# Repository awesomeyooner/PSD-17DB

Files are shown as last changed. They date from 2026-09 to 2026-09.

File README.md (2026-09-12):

# PSD-17DB
This is a breakout board mainly for the DRV8874, but includes other ICs that help with integrating FOC. About the name, it is short for "Polar Stepper Drive 17 - Dev Board". Polar because I like polar bears and 17 for usage with NEMA 17 stepper motors. 

I designed this to go ontop of my [Tiny Thinker STM32](https://github.com/awesomeyooner/Tiny-Thinker) board.

## Features

- Dual [DRV8874 DC Motor Drivers](https://www.ti.com/lit/ds/symlink/drv8874.pdf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) to control each phase
- [TPS16630](https://www.ti.com/lit/ds/symlink/tps1663.pdf?ts=1789169253557&ref_url=https%253A%252F%252Fwww.mouser.com%252F) mainly for inrush current protection (due to high capacitance)
- [BL9342 5V Step down converter](https://www.alldatasheet.com/datasheet-pdf/view/1033628/BELLING/BL9342.html) for powering the MCU using a battery
- Integrated [CAN Transciever](https://www.ti.com/lit/ds/symlink/sn65hvd230.pdf) for `CAN2.0B`
- [32Kbit SPI EEPROM](https://www.st.com/resource/en/datasheet/m95320-w.pdf) for storing parameters like `CAN ID`, `Eccentricity Offsets`, `Electrical Offset`, etc
- 4 [WS2812B RGB LEDs](https://mm.digikey.com/Volume0/opasdata/d220001/medias/docus/8903/XL-0807RGBC-WS2812B.pdf) for status lights
- R-Divider for input voltage sensing using ADC

## Pictures

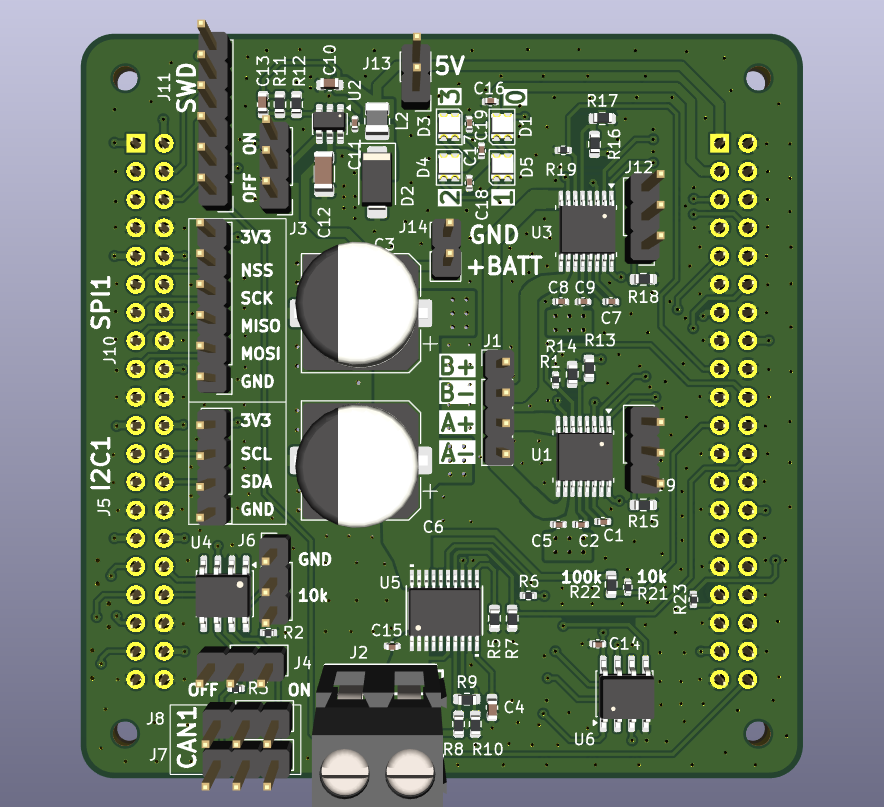
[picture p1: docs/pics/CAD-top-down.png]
CAD-top-down


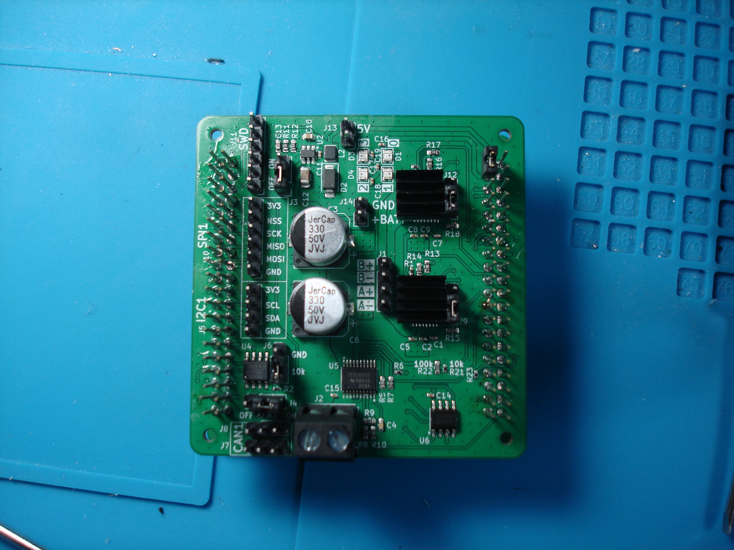
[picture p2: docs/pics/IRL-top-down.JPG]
IRL-top-down


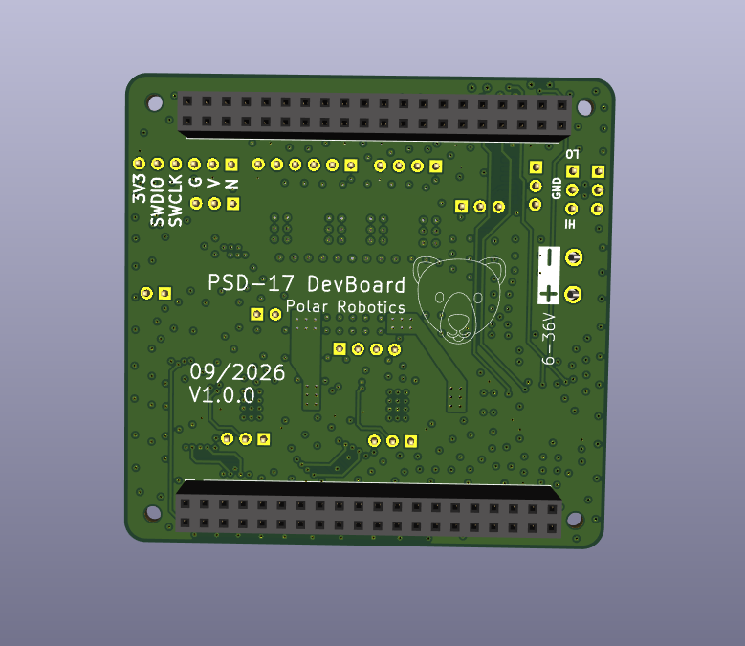
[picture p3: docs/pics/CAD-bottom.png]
CAD-bottom


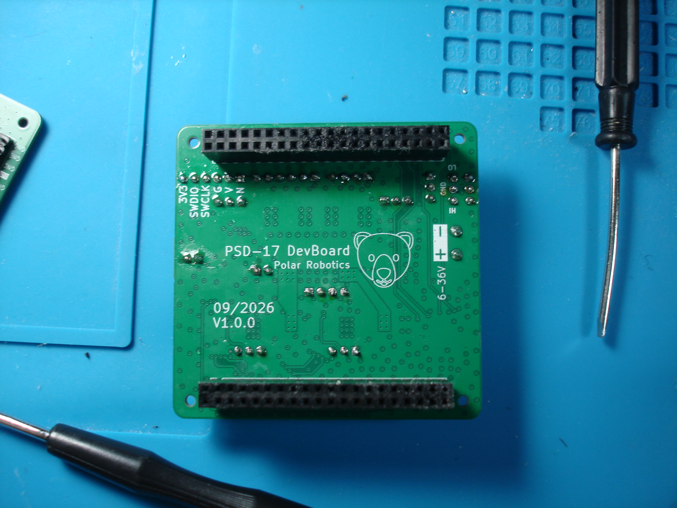
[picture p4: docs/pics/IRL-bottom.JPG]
IRL-bottom


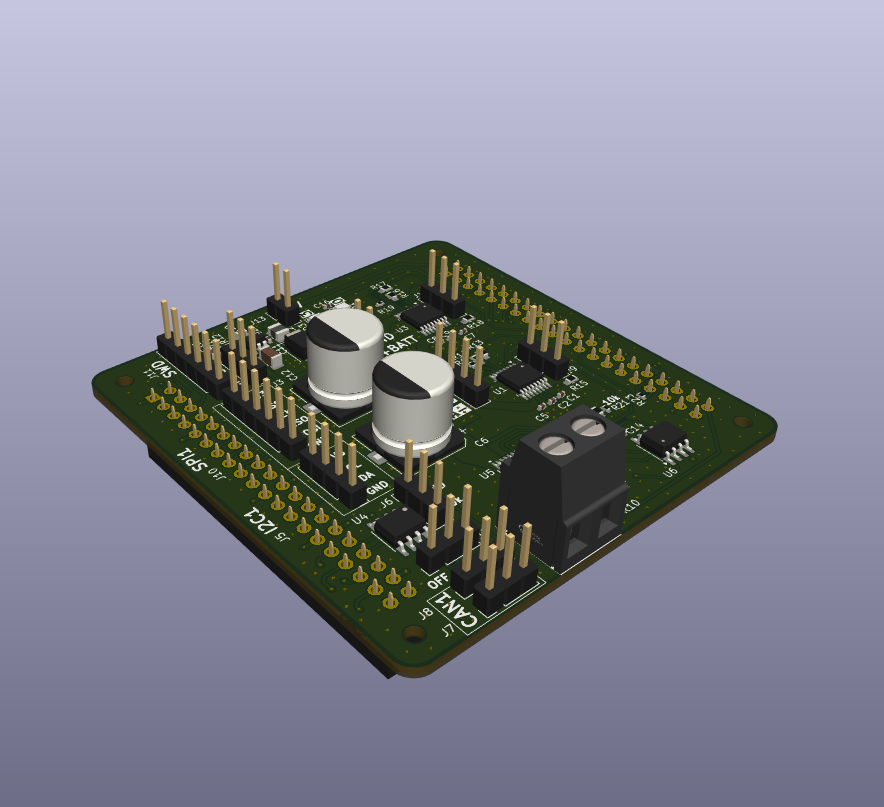
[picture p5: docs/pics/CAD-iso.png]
CAD-iso


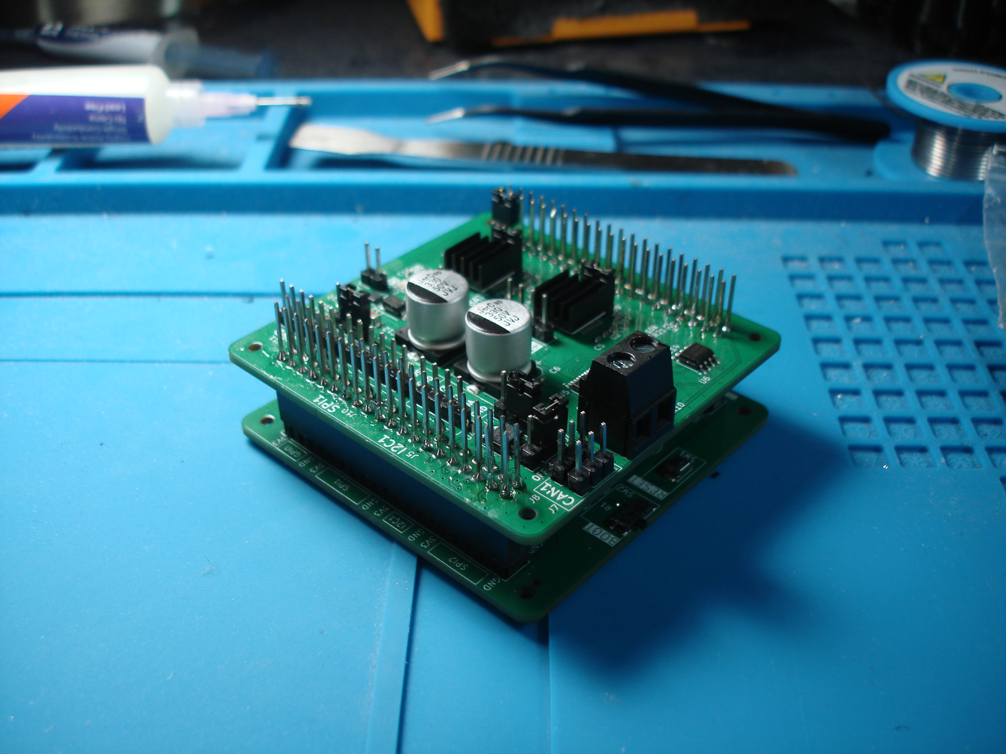
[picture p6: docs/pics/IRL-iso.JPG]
IRL-iso


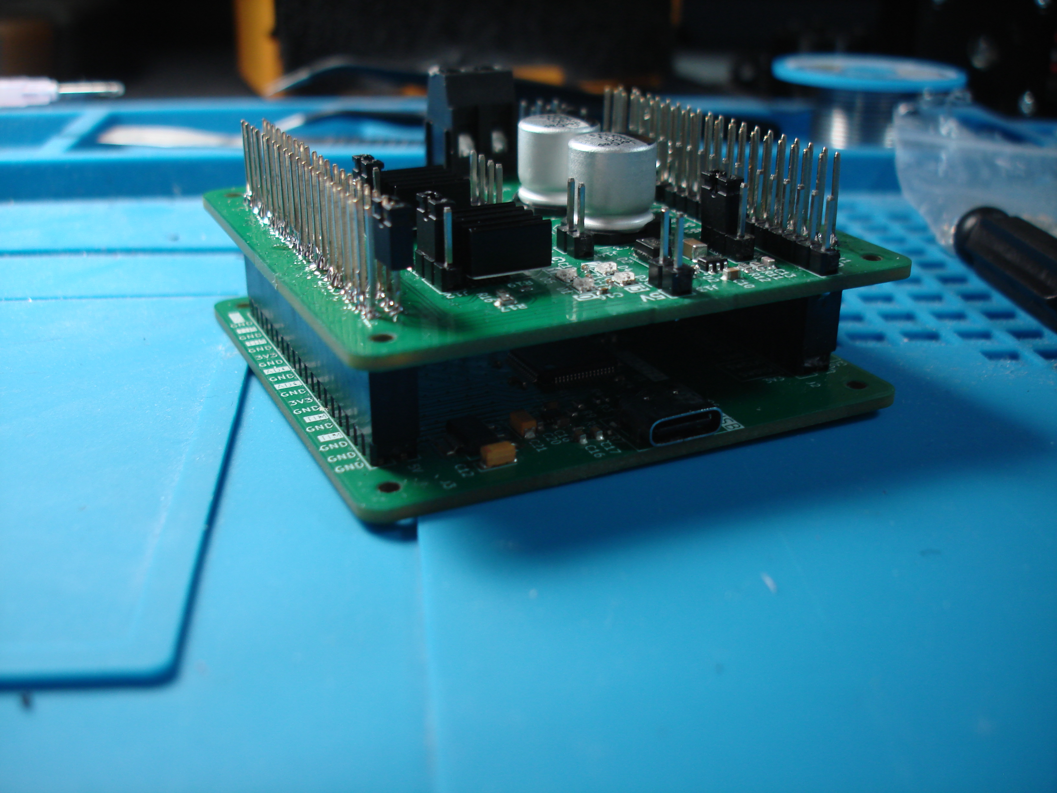
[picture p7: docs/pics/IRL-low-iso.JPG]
IRL-low-iso


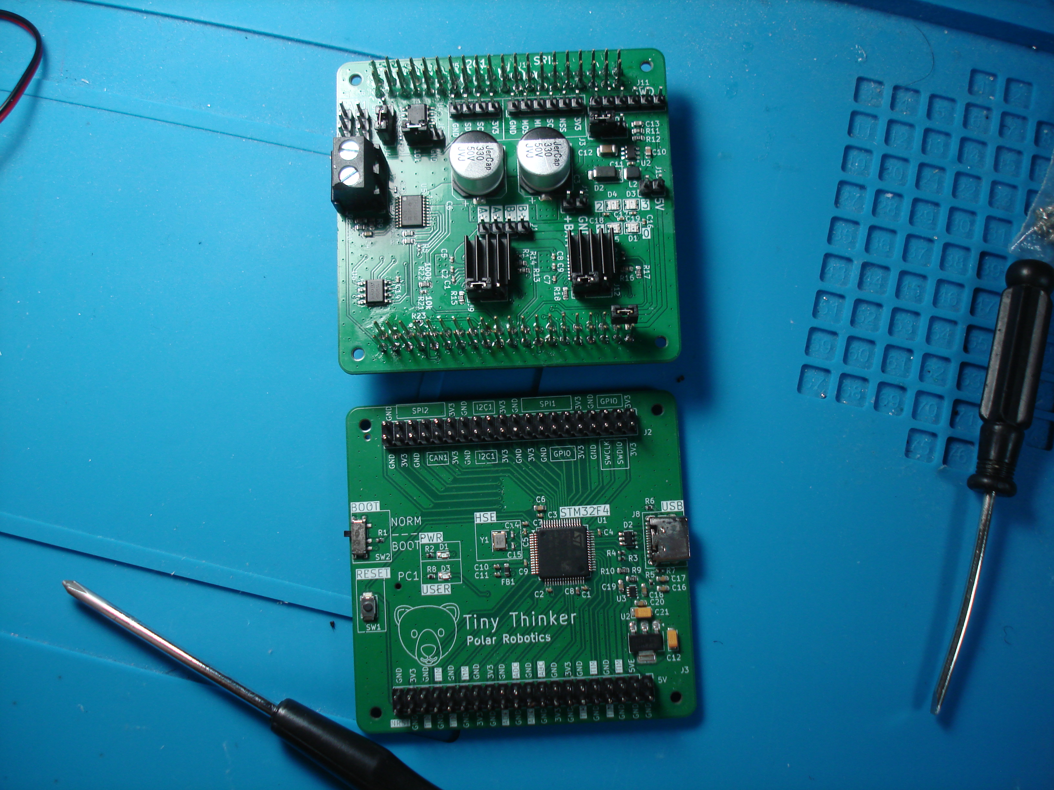
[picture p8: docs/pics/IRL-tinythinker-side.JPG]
IRL-tinythinker-side


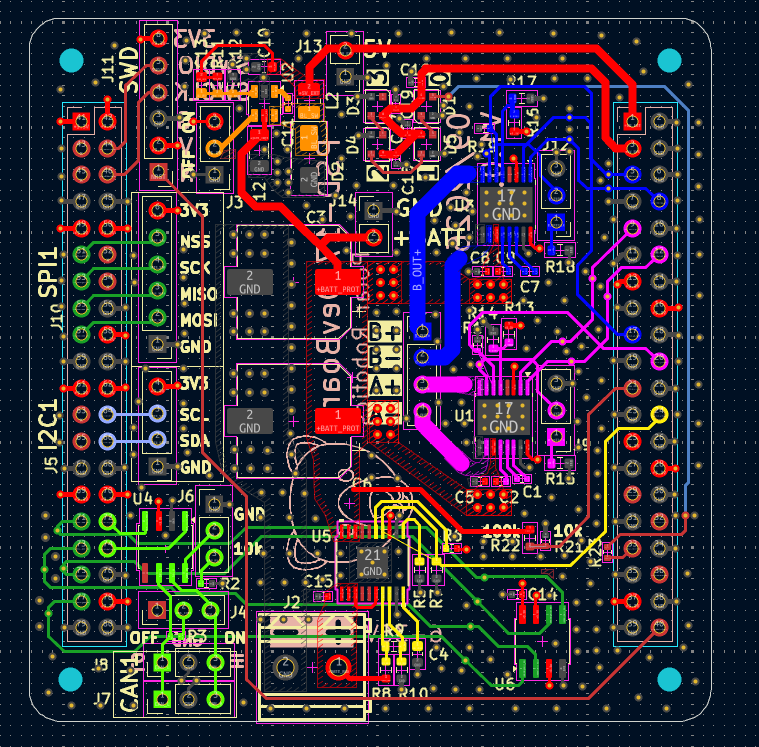
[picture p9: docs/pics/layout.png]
layout


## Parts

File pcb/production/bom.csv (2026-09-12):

Designator | Footprint | Quantity | Value | LCSC Part #
C1, C7 | 0402 | 2 | 22nF | C1532
C10 | 0603 | 1 | 10uF | C96446
C11, C14, C15, C16, C17, C18, C19, C2, C5, C8, C9 | 0402 | 11 | 100nF | C307331
C12 | 1206 | 1 | 4.7uF | C29823
C13 | 0603 | 1 | 33pF | C1663
C3, C6 | CP_Elec_10x10.5 | 2 | 330uF | C46550419
C4 | 0603 | 1 | 33nF | C21117
D1, D3, D4, D5 | LED_WS2812B-2020_PLCC4_2.0x2.0mm | 4 | WS2812B-2020 | C3646929
D2 | D_SMA | 1 | D_Schottky | C2480
J1, J5 | PinHeader_1x04_P2.54mm_Vertical | 2 | Conn_01x04_Pin
J10, J11 | PinHeader_1x06_P2.54mm_Vertical | 2 | Conn_01x06_Pin
J12, J3, J4, J6, J7, J8, J9 | PinHeader_1x03_P2.54mm_Vertical | 7 | Conn_01x03_Pin
J13, J14 | PinHeader_1x02_P2.54mm_Vertical | 2 | Conn_01x02_Pin
J2 | CONN-TH_2P-P5.08_DB128L-5.08-2P-BK-S | 1 | Screw_Terminal_01x02 | C430601
L2 | 1008 | 1 | 4u7 | C5832360
R1, R19 | 0402 | 2 | 2k2 | C25879
R10, R15, R18 | 0603 | 3 | 20k | C4184
R11 | 0603 | 1 | 124k | C22788
R12 | 0603 | 1 | 23k7 | C2933175
R13, R16 | 0603 | 2 | 15k | C22809
R14, R17 | 0603 | 2 | 75k | C23242
R2, R21, R6 | 0402 | 3 | 10k | C25744
R22, R9 | 0603 | 2 | 100k | C25803
R23 | 0402 | 1 | 470 | C25117
R3 | 0402 | 1 | 120 | C25079
R5 | 0603 | 1 | 3k | C4211
R7 | 0603 | 1 | 18k | C25810
R8 | 0603 | 1 | 510k | C23192
U1, U3 | HTSSOP-16-1EP_4.4x5mm_P0.65mm_EP3.4x5mm_Mask2.46x2.31mm | 2 | DRV8874 | C1855818
U2 | SOT-23-6 | 1 | BL9342 | C93176
U4 | SOIC-8_3.9x4.9mm_P1.27mm | 1 | SN65HVD230 | C12084
U5 | HTSSOP20_PWP_TEX | 1 | TPS16630PWPR | C1849461
U6 | SO-8_3.9x4.9mm_P1.27mm | 1 | M95320-WMN6TP | C283459
U7 | TinyThinker_HAT | 1 | TinyThinker_J1 | C1525

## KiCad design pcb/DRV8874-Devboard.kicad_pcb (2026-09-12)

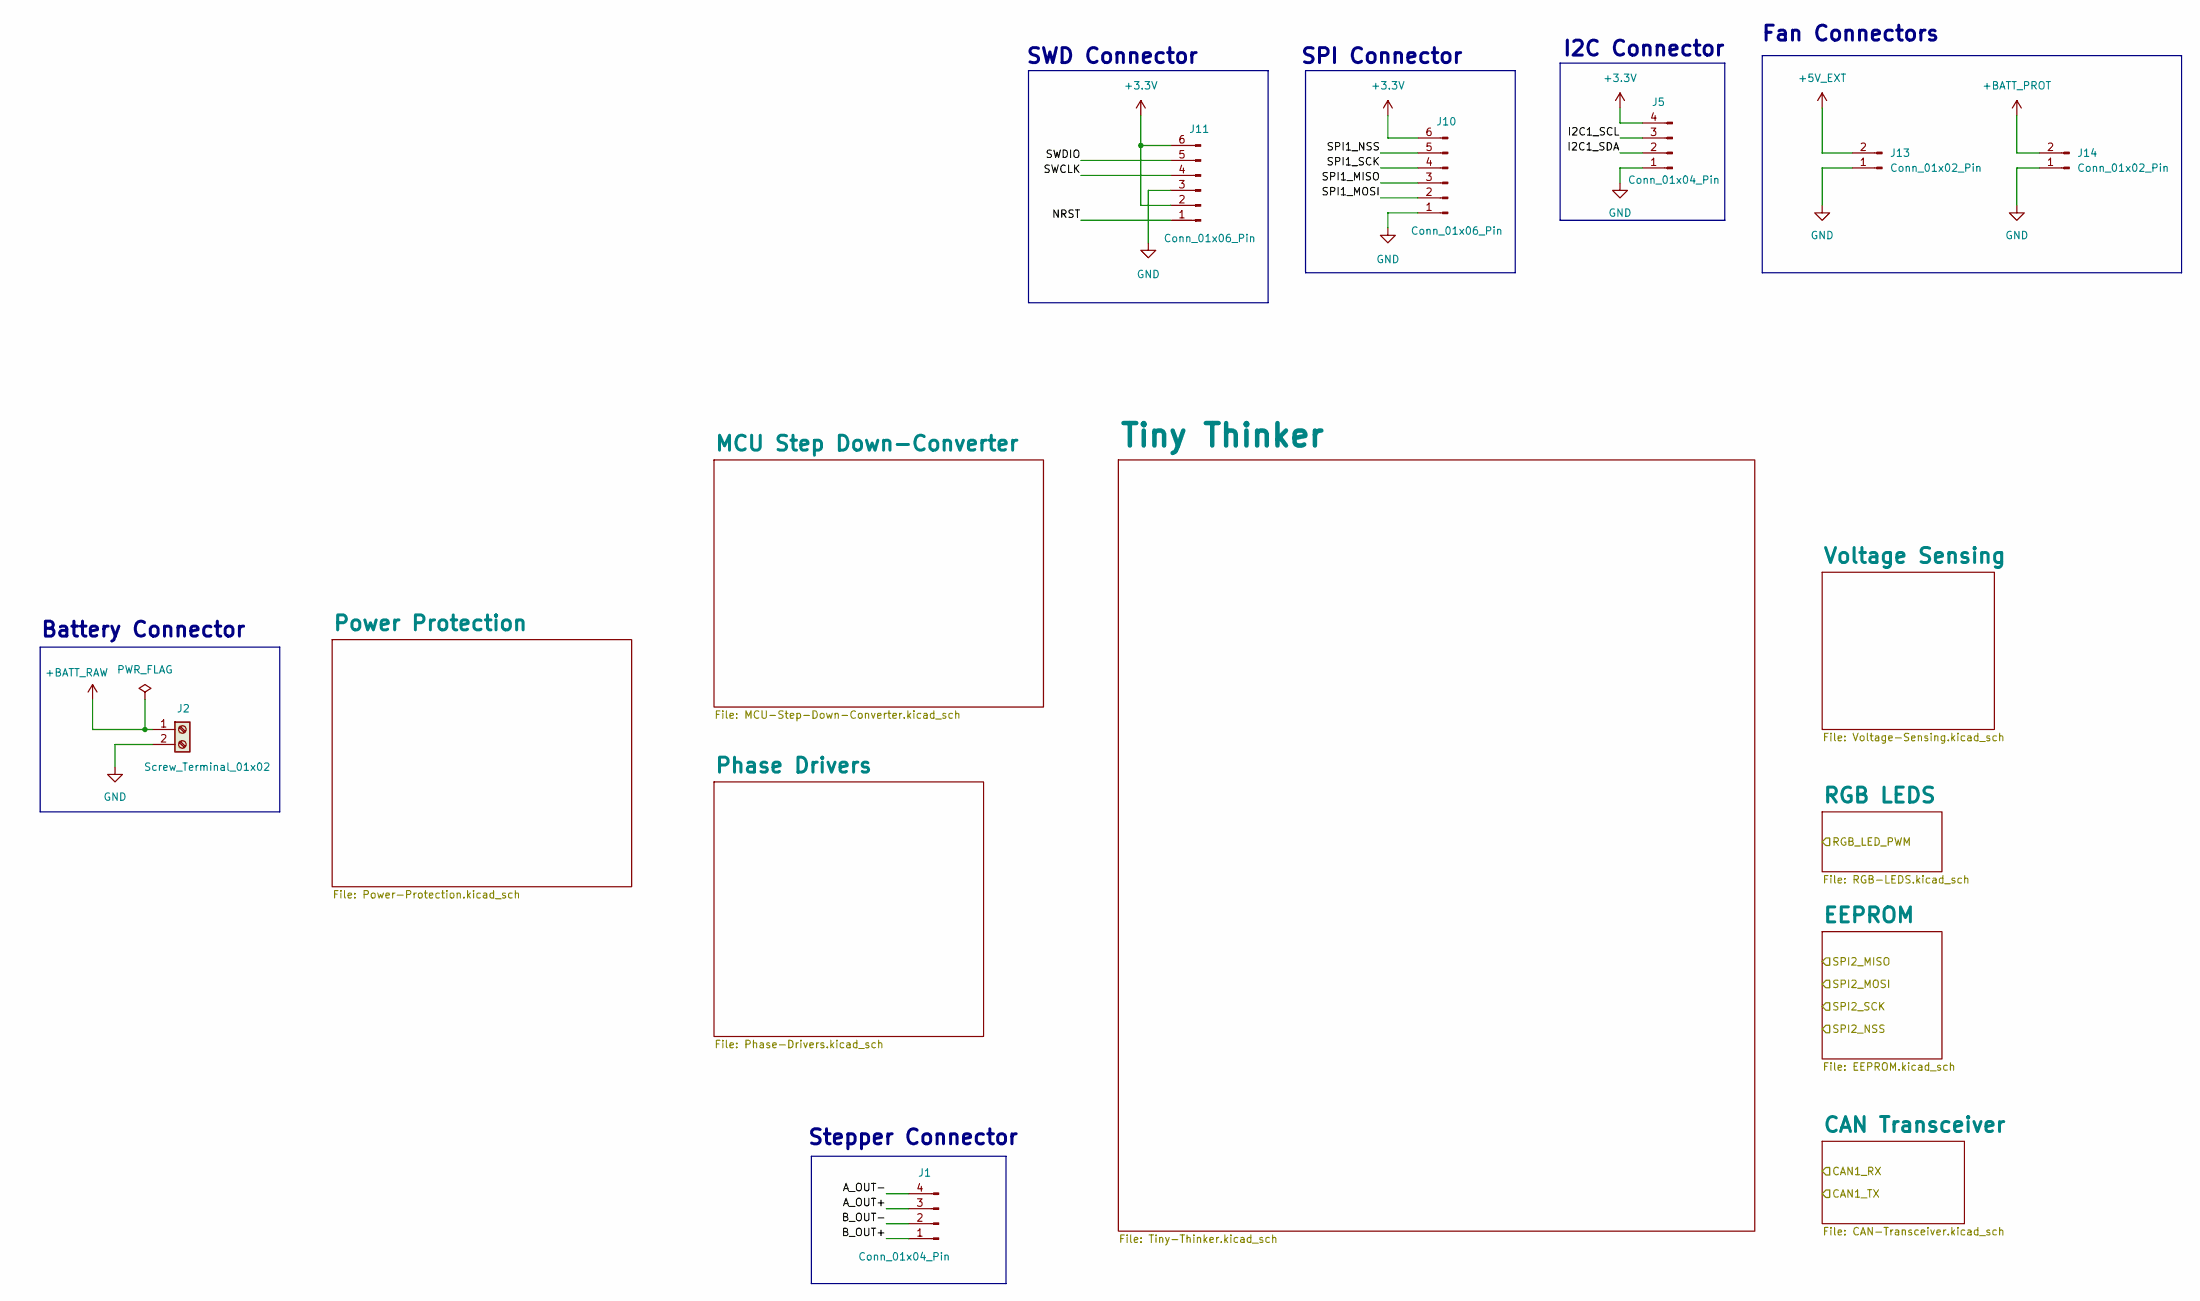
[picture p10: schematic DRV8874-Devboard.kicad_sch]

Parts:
J1, J5: Conn_01x04_Pin; PinHeader_1x04_P2.54mm_Vertical
J2: Screw_Terminal_01x02; CONN-TH_2P-P5.08_DB128L-5.08-2P-BK-S; JLCPCB Part # C430601
J10, J11: Conn_01x06_Pin; PinHeader_1x06_P2.54mm_Vertical
J13, J14: Conn_01x02_Pin; PinHeader_1x02_P2.54mm_Vertical

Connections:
+3.3V: J5.4, J10.6, J11.2, J11.6; also elsewhere on the board
+5V_EXT: J13.2; also elsewhere on the board
+BATT_PROT: J14.2; also elsewhere on the board
+BATT_RAW: J2.1; also elsewhere on the board
/A_OUT+: J1.3
/A_OUT-: J1.4
/B_OUT+: J1.1
/B_OUT-: J1.2
/I2C1_SCL: J5.3
/I2C1_SDA: J5.2
/NRST: J11.1
/SPI1_MISO: J10.3
/SPI1_MOSI: J10.2
/SPI1_NSS: J10.5
/SPI1_SCK: J10.4
/SWCLK: J11.4
/SWDIO: J11.5
GND: J2.2, J5.1, J10.1, J11.3, J13.1, J14.1; also elsewhere on the board

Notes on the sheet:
SWD Connector
Fan Connectors
Battery Connector
SPI Connector
Stepper Connector
I2C Connector

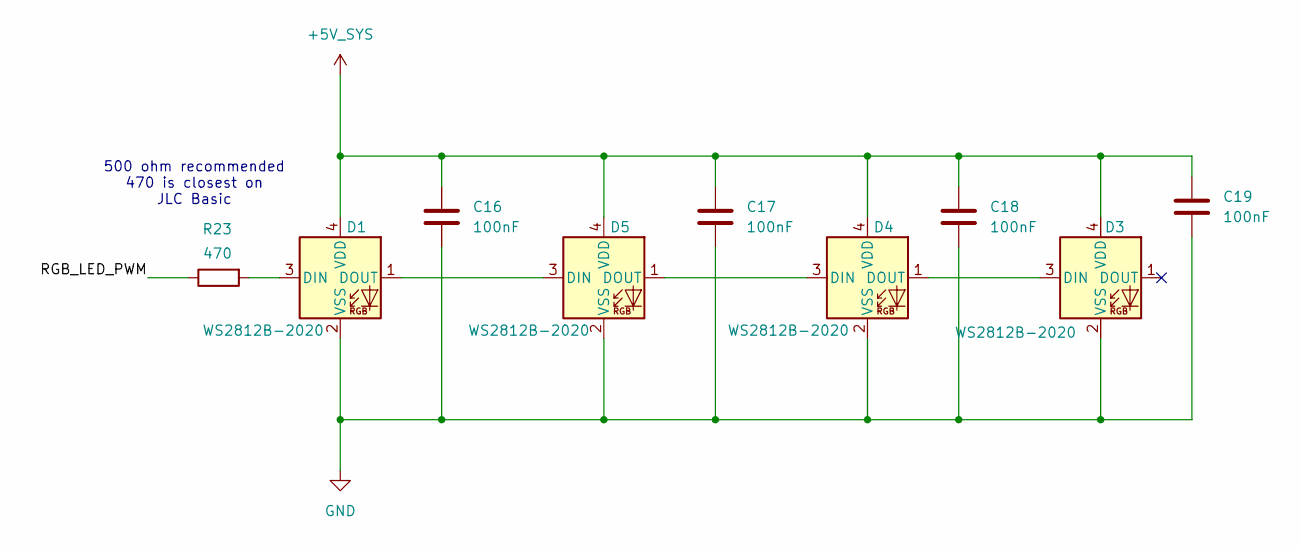
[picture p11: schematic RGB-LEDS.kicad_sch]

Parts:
C16, C17, C18, C19: 100nF; C_0402_1005Metric; JLCPCB Part # C307331
D1, D3, D4, D5: WS2812B-2020; LED_WS2812B-2020_PLCC4_2.0x2.0mm; JLCPCB Part # C3646929
R23: 470; R_0402_1005Metric; JLCPCB Part # C25117

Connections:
+5V_SYS: C16.1, C17.1, C18.1, C19.1, D1.4 (VDD), D3.4 (VDD), D4.4 (VDD), D5.4 (VDD); also elsewhere on the board
/RGB LEDS/RGB_LED_PWM: R23.1
GND: C16.2, C17.2, C18.2, C19.2, D1.2 (VSS), D3.2 (VSS), D4.2 (VSS), D5.2 (VSS); also elsewhere on the board
unnamed: D1.3 (DIN), R23.2
unnamed: D1.1 (DOUT), D5.3 (DIN)
unnamed: D3.3 (DIN), D4.1 (DOUT)
unnamed: D4.3 (DIN), D5.1 (DOUT)

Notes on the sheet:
500 ohm recommended 470 is closest on JLC Basic

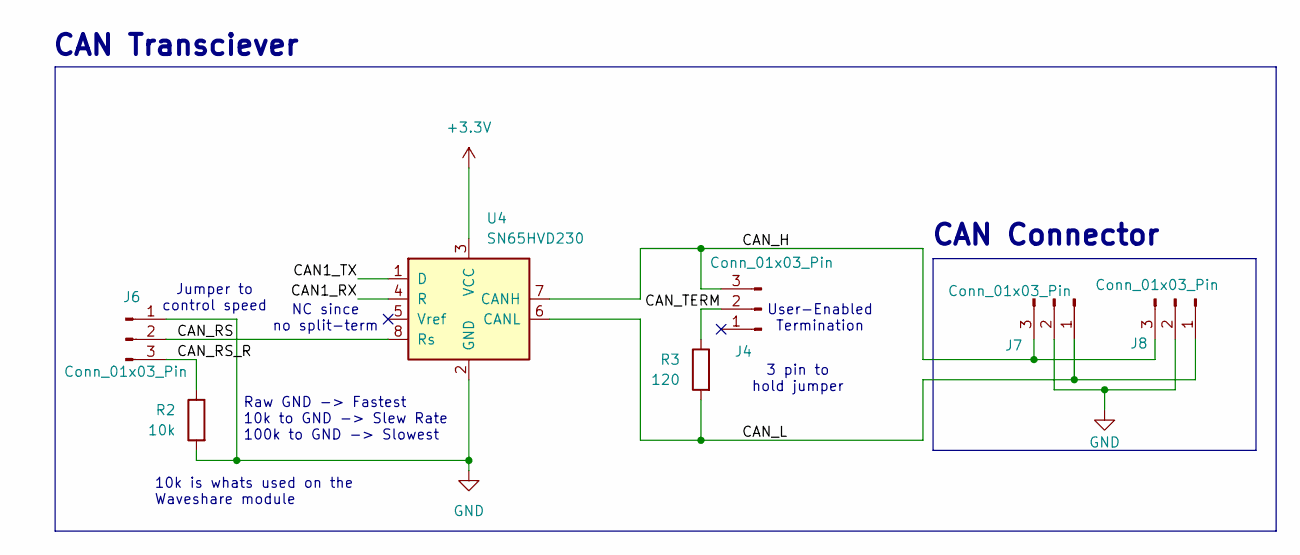
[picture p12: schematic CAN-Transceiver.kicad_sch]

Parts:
J4, J6, J7, J8: Conn_01x03_Pin; PinHeader_1x03_P2.54mm_Vertical
R2: 10k; R_0402_1005Metric; JLCPCB Part # C25744
R3: 120; R_0402_1005Metric; JLCPCB Part # C25079
U4: SN65HVD230; SOIC-8_3.9x4.9mm_P1.27mm; JLCPCB Part # C12084

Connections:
+3.3V: U4.3 (VCC); also elsewhere on the board
/CAN Transceiver/CAN1_RX: U4.4 (R)
/CAN Transceiver/CAN1_TX: U4.1 (D)
/CAN Transceiver/CAN_H: J4.3, J7.3, J8.3, U4.7 (CANH)
/CAN Transceiver/CAN_L: J7.1, J8.1, R3.2, U4.6 (CANL)
/CAN Transceiver/CAN_RS: J6.2, U4.8 (Rs)
/CAN Transceiver/CAN_RS_R: J6.3, R2.1
/CAN Transceiver/CAN_TERM: J4.2, R3.1
GND: J6.1, J7.2, J8.2, R2.2, U4.2 (GND); also elsewhere on the board

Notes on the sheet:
Jumper to control speed
10k is whats used on the Waveshare module
CAN Connector
CAN Transciever
Raw GND -> Fastest 10k to GND -> Slew Rate 100k to GND -> Slowest
3 pin to hold jumper
User-Enabled Termination
NC since no split-term

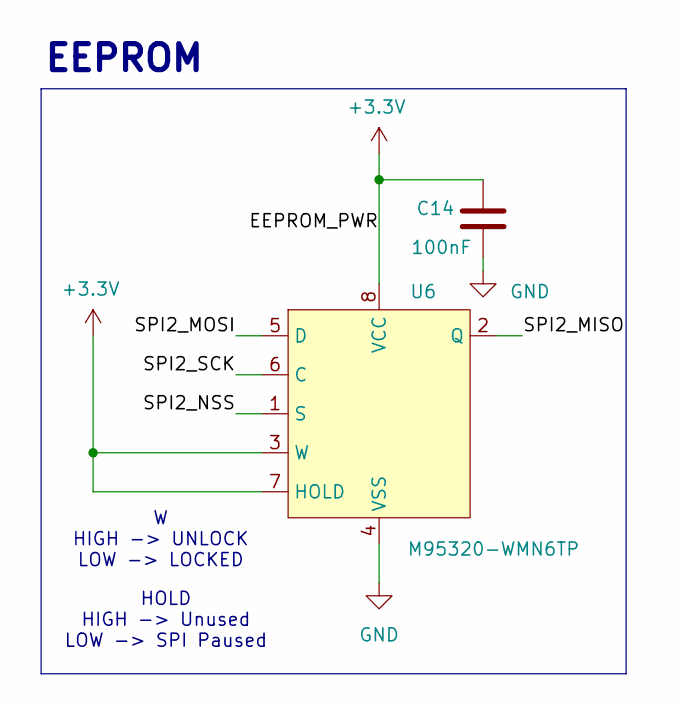
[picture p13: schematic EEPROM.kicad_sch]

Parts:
C14: 100nF; C_0402_1005Metric; JLCPCB Part # C307331
U6: M95320-WMN6TP; SO-8_3.9x4.9mm_P1.27mm; JLCPCB Part # C283459

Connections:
+3.3V: C14.1, U6.3 (W), U6.7 (HOLD), U6.8 (VCC); also elsewhere on the board
/EEPROM/SPI2_MISO: U6.2 (Q)
/EEPROM/SPI2_MOSI: U6.5 (D)
/EEPROM/SPI2_NSS: U6.1 (S)
/EEPROM/SPI2_SCK: U6.6 (C)
GND: C14.2, U6.4 (VSS); also elsewhere on the board

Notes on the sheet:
HOLD HIGH -> Unused LOW -> SPI Paused
EEPROM
W HIGH -> UNLOCK LOW -> LOCKED

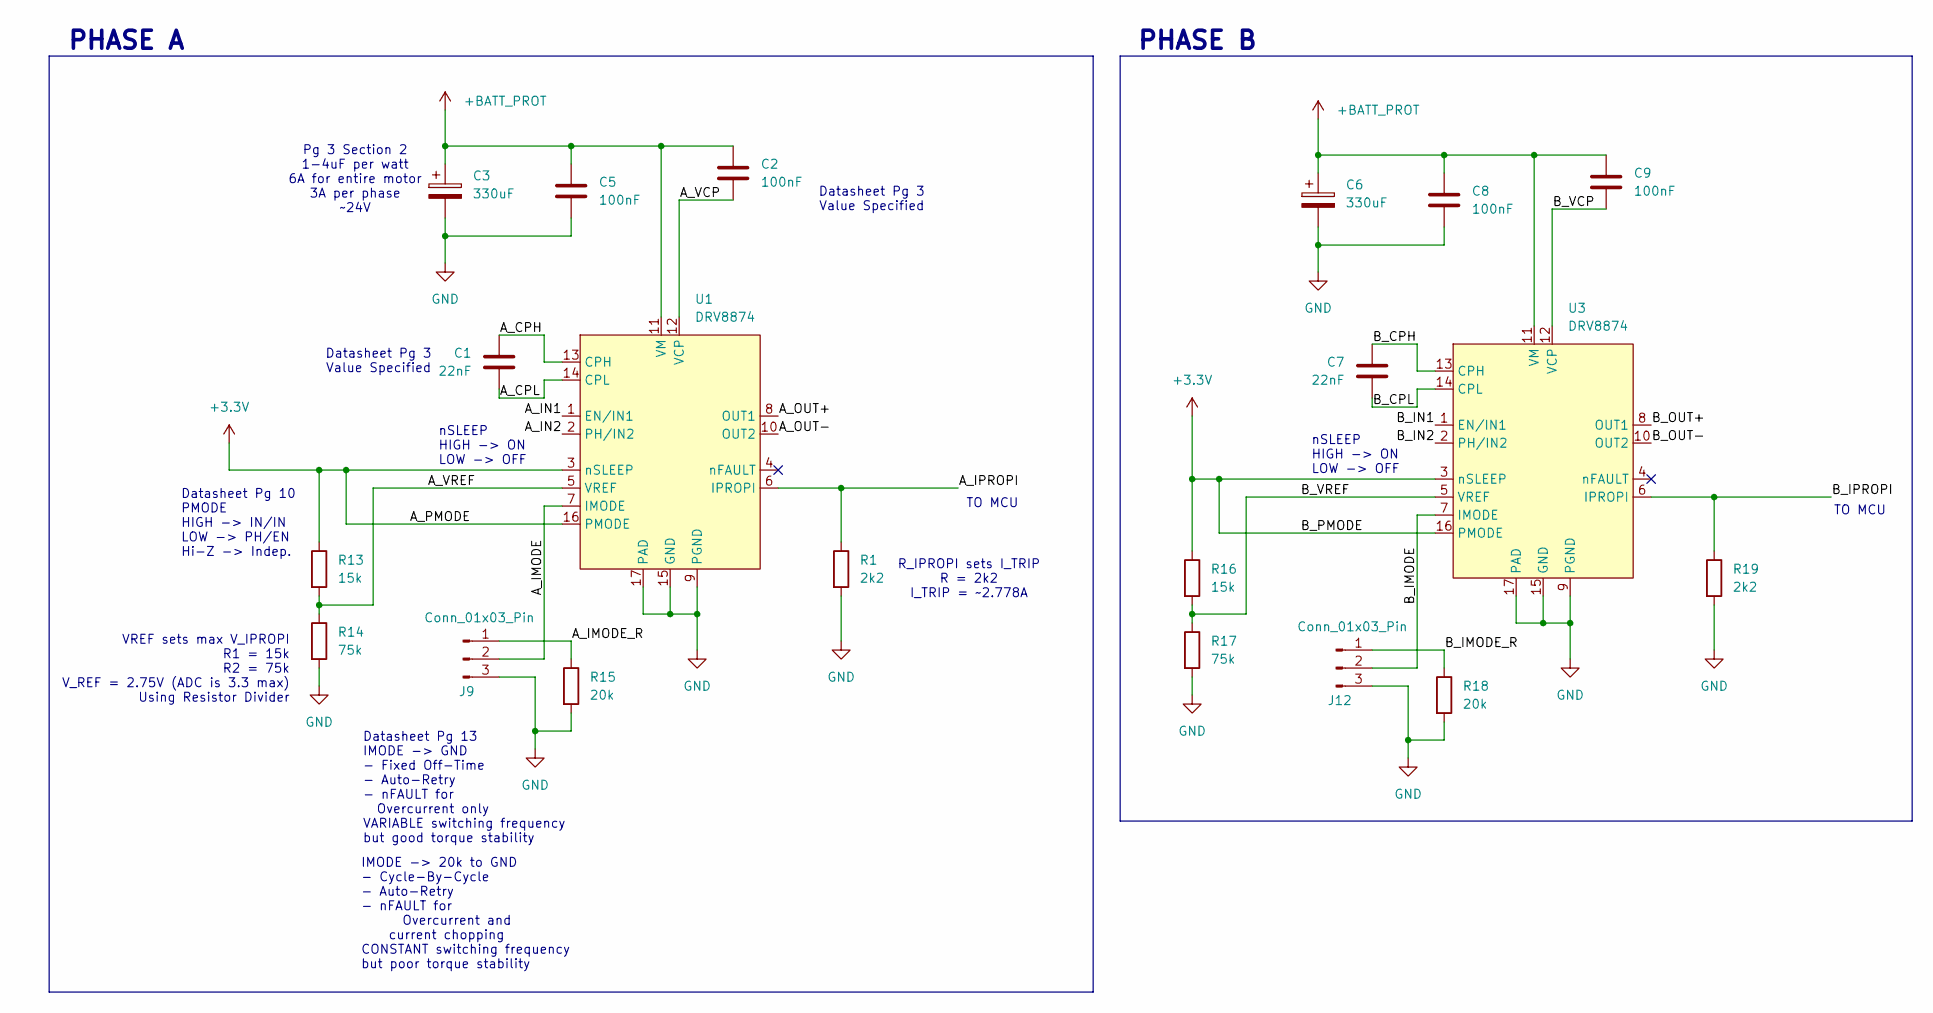
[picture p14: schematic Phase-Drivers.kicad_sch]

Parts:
C1, C7: 22nF; C_0402_1005Metric; JLCPCB Part # C1532
C2, C5, C8, C9: 100nF; C_0402_1005Metric; JLCPCB Part # C307331
C3, C6: 330uF; CP_Elec_10x10.5; JLCPCB Part # C46550419
J9, J12: Conn_01x03_Pin; PinHeader_1x03_P2.54mm_Vertical
R1, R19: 2k2; R_0402_1005Metric; JLCPCB Part # C25879
R13, R16: 15k; R_0603_1608Metric; JLCPCB Part # C22809
R14, R17: 75k; R_0603_1608Metric; JLCPCB Part # C23242
R15, R18: 20k; R_0603_1608Metric; JLCPCB Part # C4184
U1, U3: DRV8874; HTSSOP-16-1EP_4.4x5mm_P0.65mm_EP3.4x5mm_Mask2.46x2.31mm; JLCPCB Part # C1855818

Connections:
+3.3V: R13.1, R16.1, U1.3 (nSLEEP), U1.16 (PMODE), U3.3 (nSLEEP), U3.16 (PMODE); also elsewhere on the board
+BATT_PROT: C2.1, C3.1, C5.1, C6.1, C8.1, C9.1, U1.11 (VM), U3.11 (VM); also elsewhere on the board
/Phase Drivers/A_CPH: C1.1, U1.13 (CPH)
/Phase Drivers/A_CPL: C1.2, U1.14 (CPL)
/Phase Drivers/A_IMODE: J9.2, U1.7 (IMODE)
/Phase Drivers/A_IMODE_R: J9.1, R15.1
/Phase Drivers/A_IN1: U1.1 (EN/IN1)
/Phase Drivers/A_IN2: U1.2 (PH/IN2)
/Phase Drivers/A_IPROPI: R1.1, U1.6 (IPROPI)
/Phase Drivers/A_OUT+: U1.8 (OUT1)
/Phase Drivers/A_OUT-: U1.10 (OUT2)
/Phase Drivers/A_VCP: C2.2, U1.12 (VCP)
/Phase Drivers/A_VREF: R13.2, R14.1, U1.5 (VREF)
/Phase Drivers/B_CPH: C7.1, U3.13 (CPH)
/Phase Drivers/B_CPL: C7.2, U3.14 (CPL)
/Phase Drivers/B_IMODE: J12.2, U3.7 (IMODE)
/Phase Drivers/B_IMODE_R: J12.1, R18.1
/Phase Drivers/B_IN1: U3.1 (EN/IN1)
/Phase Drivers/B_IN2: U3.2 (PH/IN2)
/Phase Drivers/B_IPROPI: R19.1, U3.6 (IPROPI)
/Phase Drivers/B_OUT+: U3.8 (OUT1)
/Phase Drivers/B_OUT-: U3.10 (OUT2)
/Phase Drivers/B_VCP: C9.2, U3.12 (VCP)
/Phase Drivers/B_VREF: R16.2, R17.1, U3.5 (VREF)
GND: C3.2, C5.2, C6.2, C8.2, J9.3, J12.3, R1.2, R14.2, R15.2, R17.2, R18.2, R19.2, U1.9 (PGND), U1.15 (GND), U1.17 (PAD), U3.9 (PGND), U3.15 (GND), U3.17 (PAD); also elsewhere on the board

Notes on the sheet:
Datasheet Pg 3 Value Specified
PHASE B
Datasheet Pg 13 IMODE -> GND - Fixed Off-Time - Auto-Retry - nFAULT for Overcurrent only VARIABLE switching frequency but good torque stability
PHASE A
nSLEEP HIGH -> ON LOW -> OFF
VREF sets max V_IPROPI R1 = 15k R2 = 75k V_REF = 2.75V (ADC is 3.3 max) Using Resistor Divider
TO MCU
IMODE -> 20k to GND - Cycle-By-Cycle - Auto-Retry - nFAULT for Overcurrent and current chopping CONSTANT switching frequency but poor torque stability
Pg 3 Section 2 1-4uF per watt 6A for entire motor 3A per phase ~24V
R_IPROPI sets I_TRIP R = 2k2 I_TRIP = ~2.778A
Datasheet Pg 10 PMODE HIGH -> IN/IN LOW -> PH/EN Hi-Z -> Indep.

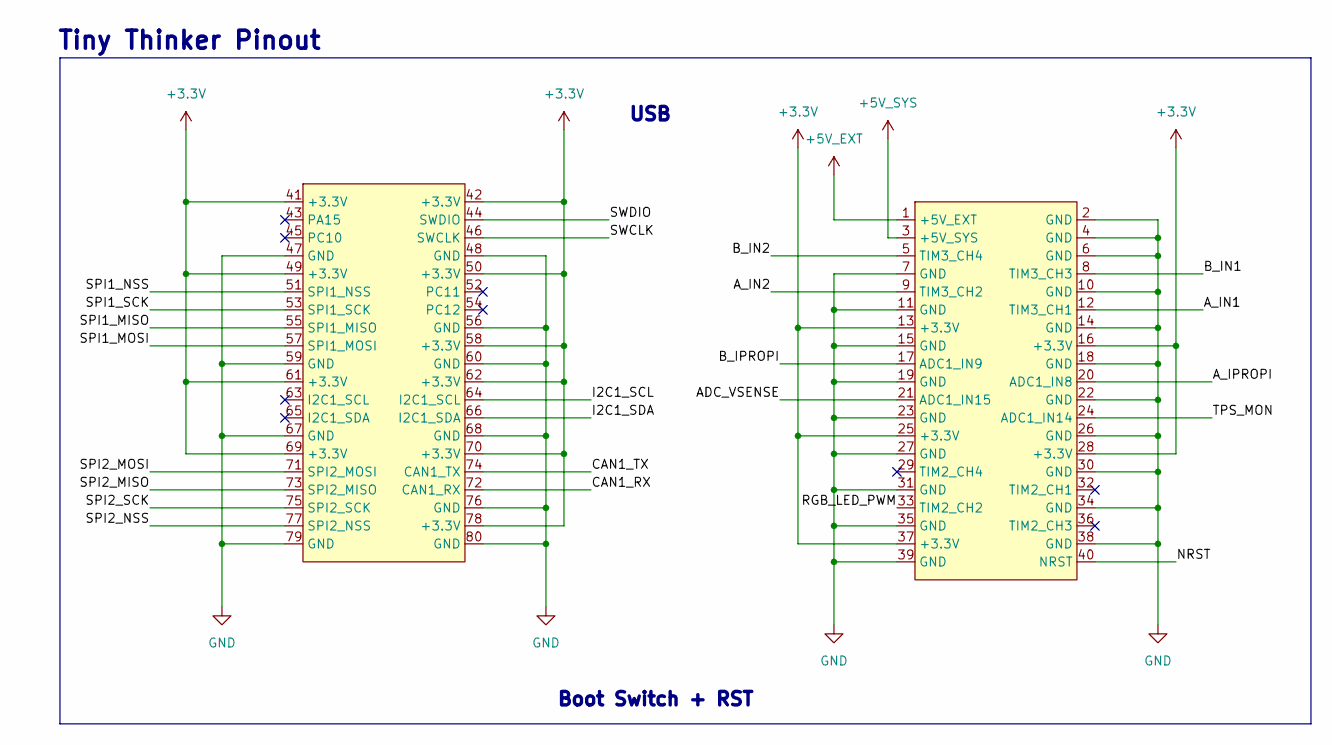
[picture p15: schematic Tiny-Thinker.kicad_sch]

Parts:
U7: TinyThinker_J1; TinyThinker_HAT

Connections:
+3.3V: U7.13 (+3.3V), U7.16 (+3.3V), U7.25 (+3.3V), U7.28 (+3.3V), U7.37 (+3.3V), U7.41 (+3.3V), U7.42 (+3.3V), U7.49 (+3.3V), U7.50 (+3.3V), U7.58 (+3.3V), U7.61 (+3.3V), U7.62 (+3.3V), U7.69 (+3.3V), U7.70 (+3.3V), U7.78 (+3.3V); also elsewhere on the board
+5V_EXT: U7.1 (+5V_EXT); also elsewhere on the board
+5V_SYS: U7.3 (+5V_SYS); also elsewhere on the board
/Tiny Thinker/ADC_VSENSE: U7.21 (ADC1_IN15)
/Tiny Thinker/A_IN1: U7.12 (TIM3_CH1)
/Tiny Thinker/A_IN2: U7.9 (TIM3_CH2)
/Tiny Thinker/A_IPROPI: U7.20 (ADC1_IN8)
/Tiny Thinker/B_IN1: U7.8 (TIM3_CH3)
/Tiny Thinker/B_IN2: U7.5 (TIM3_CH4)
/Tiny Thinker/B_IPROPI: U7.17 (ADC1_IN9)
/Tiny Thinker/CAN1_RX: U7.72 (CAN1_RX)
/Tiny Thinker/CAN1_TX: U7.74 (CAN1_TX)
/Tiny Thinker/I2C1_SCL: U7.64 (I2C1_SCL)
/Tiny Thinker/I2C1_SDA: U7.66 (I2C1_SDA)
/Tiny Thinker/NRST: U7.40 (NRST)
/Tiny Thinker/RGB_LED_PWM: U7.33 (TIM2_CH2)
/Tiny Thinker/SPI1_MISO: U7.55 (SPI1_MISO)
/Tiny Thinker/SPI1_MOSI: U7.57 (SPI1_MOSI)
/Tiny Thinker/SPI1_NSS: U7.51 (SPI1_NSS)
/Tiny Thinker/SPI1_SCK: U7.53 (SPI1_SCK)
/Tiny Thinker/SPI2_MISO: U7.73 (SPI2_MISO)
/Tiny Thinker/SPI2_MOSI: U7.71 (SPI2_MOSI)
/Tiny Thinker/SPI2_NSS: U7.77 (SPI2_NSS)
/Tiny Thinker/SPI2_SCK: U7.75 (SPI2_SCK)
/Tiny Thinker/SWCLK: U7.46 (SWCLK)
/Tiny Thinker/SWDIO: U7.44 (SWDIO)
/Tiny Thinker/TPS_MON: U7.24 (ADC1_IN14)
GND: U7.2 (GND), U7.4 (GND), U7.6 (GND), U7.7 (GND), U7.10 (GND), U7.11 (GND), U7.14 (GND), U7.15 (GND), U7.18 (GND), U7.19 (GND), U7.22 (GND), U7.23 (GND), U7.26 (GND), U7.27 (GND), U7.30 (GND), U7.31 (GND), U7.34 (GND), U7.35 (GND), U7.38 (GND), U7.39 (GND), U7.47 (GND), U7.48 (GND), U7.56 (GND), U7.59 (GND), U7.60 (GND), U7.67 (GND), U7.68 (GND), U7.76 (GND), U7.79 (GND), U7.80 (GND); also elsewhere on the board

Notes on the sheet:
Tiny Thinker Pinout
Boot Switch + RST
USB

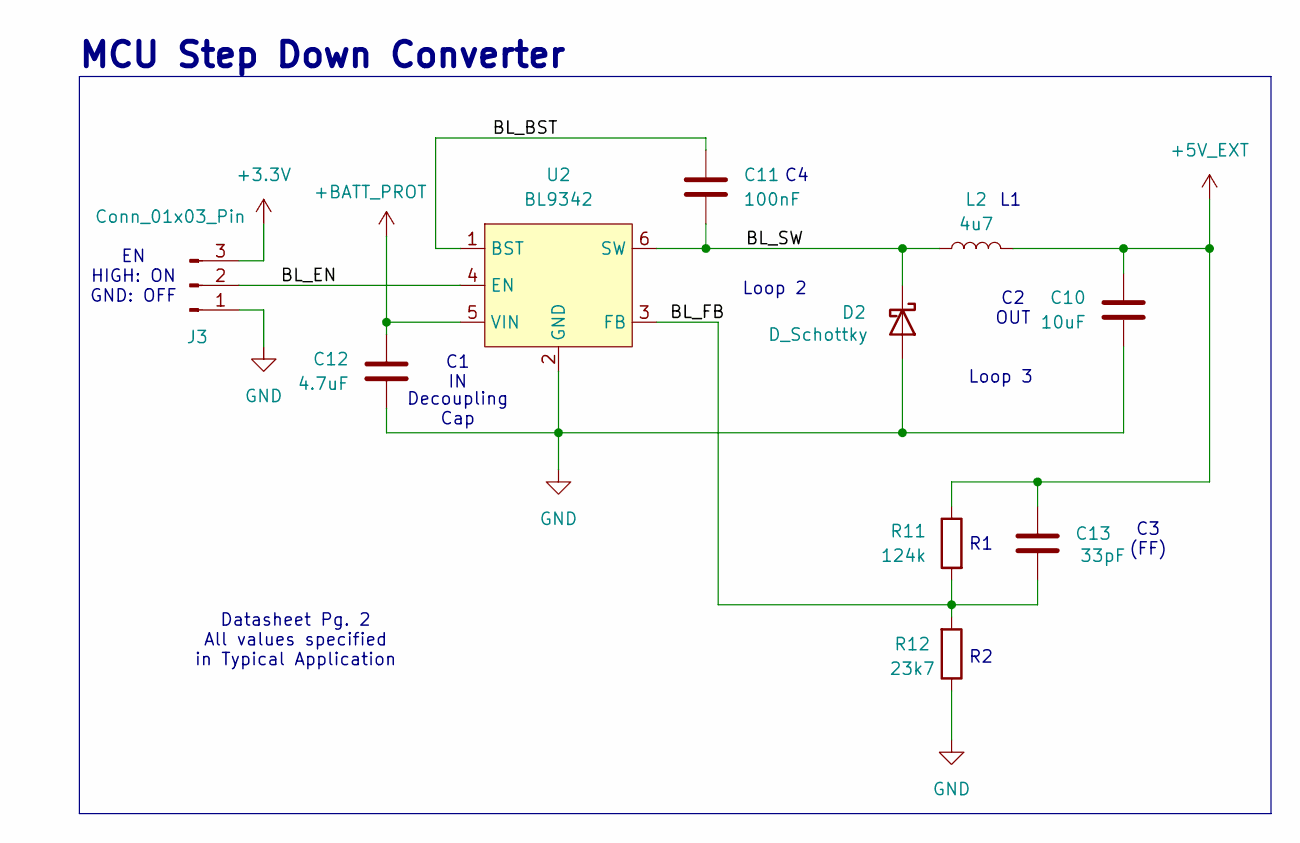
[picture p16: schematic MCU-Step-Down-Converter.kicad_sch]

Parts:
C10: 10uF; C_0603_1608Metric; JLCPCB Part # C96446
C11: 100nF; C_0402_1005Metric; JLCPCB Part # C307331
C12: 4.7uF; C_1206_3216Metric; JLCPCB Part # C29823
C13: 33pF; C_0603_1608Metric; JLCPCB Part # C1663
D2: D_Schottky; D_SMA; JLCPCB Part # C2480
J3: Conn_01x03_Pin; PinHeader_1x03_P2.54mm_Vertical
L2: 4u7; L_1008_2520Metric; JLCPCB Part # C5832360
R11: 124k; R_0603_1608Metric; JLCPCB Part # C22788
R12: 23k7; R_0603_1608Metric; JLCPCB Part # C2933175
U2: BL9342; SOT-23-6; JLCPCB Part # C93176

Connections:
+3.3V: J3.3; also elsewhere on the board
+5V_EXT: C10.1, C13.2, L2.2, R11.1; also elsewhere on the board
+BATT_PROT: C12.1, U2.5 (VIN); also elsewhere on the board
/MCU Step Down-Converter/BL_BST: C11.1, U2.1 (BST)
/MCU Step Down-Converter/BL_EN: J3.2, U2.4 (EN)
/MCU Step Down-Converter/BL_FB: C13.1, R11.2, R12.2, U2.3 (FB)
/MCU Step Down-Converter/BL_SW: C11.2, D2.1 (K), L2.1, U2.6 (SW)
GND: C10.2, C12.2, D2.2 (A), J3.1, R12.1, U2.2 (GND); also elsewhere on the board

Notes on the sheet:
MCU Step Down Converter
C2 OUT
Datasheet Pg. 2 All values specified in Typical Application
C3 (FF)
Loop 3
Decoupling Cap
Loop 2
EN HIGH: ON GND: OFF
C1 IN

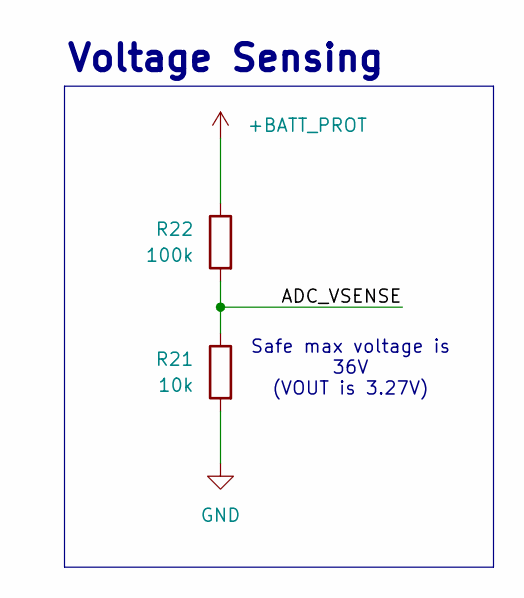
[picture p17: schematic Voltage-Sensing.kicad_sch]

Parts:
R21: 10k; R_0402_1005Metric; JLCPCB Part # C25744
R22: 100k; R_0603_1608Metric; JLCPCB Part # C25803

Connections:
+BATT_PROT: R22.1; also elsewhere on the board
/Voltage Sensing/ADC_VSENSE: R21.1, R22.2
GND: R21.2; also elsewhere on the board

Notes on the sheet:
Voltage Sensing
Safe max voltage is 36V (VOUT is 3.27V)

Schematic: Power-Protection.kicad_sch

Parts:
C4: 33nF; C_0603_1608Metric; JLCPCB Part # C21117
C15: 100nF; C_0402_1005Metric; JLCPCB Part # C307331
R5: 3k; R_0603_1608Metric; JLCPCB Part # C4211
R6: 10k; R_0402_1005Metric; JLCPCB Part # C25744
R7: 18k; R_0603_1608Metric; JLCPCB Part # C25810
R8: 510k; R_0603_1608Metric; JLCPCB Part # C23192
R9: 100k; R_0603_1608Metric; JLCPCB Part # C25803
R10: 20k; R_0603_1608Metric; JLCPCB Part # C4184
U5: TPS16630PWPR; HTSSOP20_PWP_TEX; JLCPCB Part # C1849461

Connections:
+3.3V: R6.1, U5.13 (*SHDN); also elsewhere on the board
+BATT_PROT: U5.18 (OUT), U5.19 (OUT), U5.20 (OUT); also elsewhere on the board
+BATT_RAW: C15.2, R8.1, U5.1 (IN), U5.2 (IN), U5.3 (IN), U5.6 (P_IN); also elsewhere on the board
/Power Protection/TPS_DVDT: C4.1, U5.10 (DVDT)
/Power Protection/TPS_FLT: R6.2, U5.15 (*FLT)
/Power Protection/TPS_ILIM: R5.1, U5.11 (ILIM)
/Power Protection/TPS_MON: R7.1, U5.14 (IMON)
/Power Protection/TPS_OVP: R9.2, R10.1, U5.8 (OVP)
/Power Protection/TPS_UVLO: R8.2, R9.1, U5.7 (UVLO)
GND: C4.2, C15.1, R5.2, R7.2, R10.2, U5.9 (GND), U5.12 (MODE), U5.21 (GND); also elsewhere on the board

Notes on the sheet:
Power Protection
IMON 18k ~3V @ 6A
MODE -> GND Auto-Retry
to STM32
33nF => 1A ~15ms
UVLO ~6V OVP ~38V
Datasheet Pg 28 9.2.2.2 R's Calc
Max V: 36V Min V: 6V (for DRV8874)
FLT HIGH: Norm LOW: Fault
SHDN HIGH: ON GND: OFF
100nF Decoupling Cap
I_OL = 6A

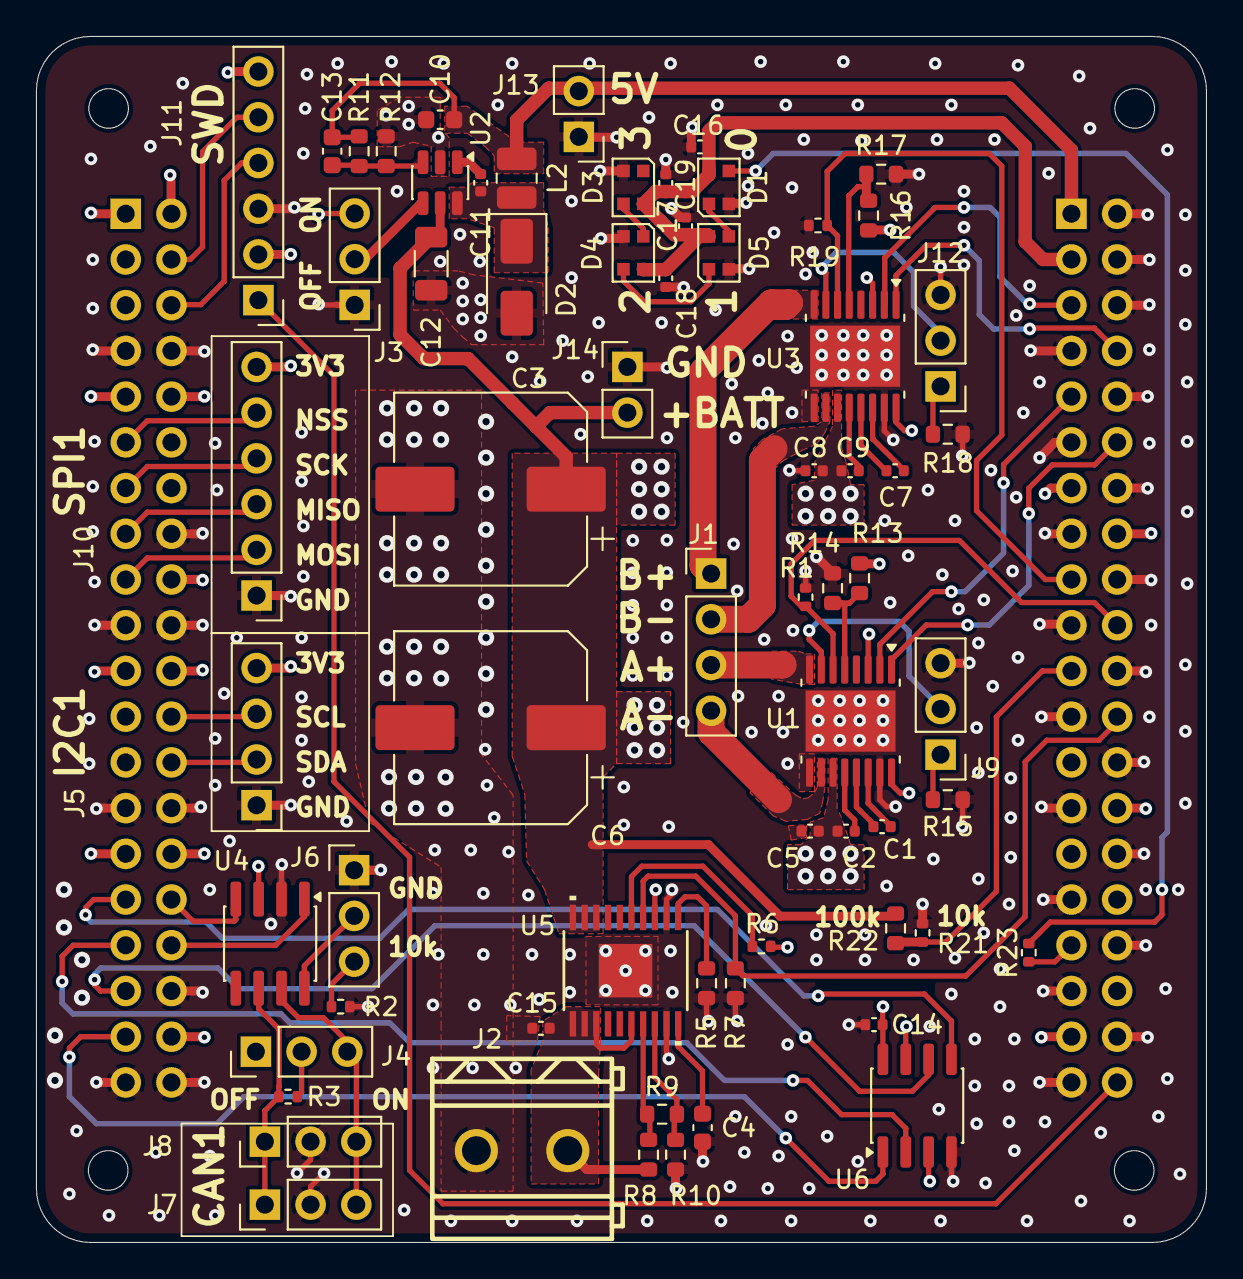
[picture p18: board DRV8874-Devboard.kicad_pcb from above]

Board: 4 copper layers, 65.0 x 67.0 mm, 67 parts (1 on the bottom side), 40 nets.

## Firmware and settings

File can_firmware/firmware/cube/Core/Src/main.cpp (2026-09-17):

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
/* Includes ------------------------------------------------------------------*/
#include "main.h"
#include "can.h"
#include "i2c.h"
#include "usb_device.h"
#include "gpio.h"

/* USER CODE BEGIN Includes */
#include "core.hpp"
/* USER CODE END Includes */


#ifdef __cplusplus
extern "C" {
#endif

void SystemClock_Config(void);

#ifdef __cplusplus
}
#endif
/**
  * @brief  The application entry point.
  * @retval int
  */
int main(void)
{

  /* MCU Configuration--------------------------------------------------------*/

  /* Reset of all peripherals, Initializes the Flash interface and the Systick. */
  HAL_Init();

  /* Configure the system clock */
  SystemClock_Config();

  /* Initialize all configured peripherals */
  MX_GPIO_Init();
  MX_USB_DEVICE_Init();
  MX_I2C1_Init();
  MX_CAN1_Init();
  /* USER CODE BEGIN 2 */
    init();
  /* USER CODE END 2 */

  /* Infinite loop */
  /* USER CODE BEGIN WHILE */
  while (1)
  {
    /* USER CODE END WHILE */

    /* USER CODE BEGIN 3 */
    update();
  }
  /* USER CODE END 3 */
}

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


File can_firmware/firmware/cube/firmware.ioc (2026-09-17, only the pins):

Mcu.UserName=STM32F446RCTx
PA11.Signal=USB_OTG_FS_DM
PA12.Signal=USB_OTG_FS_DP
PA13.Signal=SYS_JTMS-SWDIO
PA14.Signal=SYS_JTCK-SWCLK
PA9.Signal=USB_OTG_FS_VBUS
PB6.Signal=I2C1_SCL
PB7.Signal=I2C1_SDA
PB8.Signal=CAN1_RX
PB9.Signal=CAN1_TX
PC1.Signal=GPIO_Output
PH0-OSC_IN.Signal=RCC_OSC_IN
PH1-OSC_OUT.Signal=RCC_OSC_OUT

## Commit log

2026-09-12 added KiCAD files
    [CAN-Transceiver.kicad_sch, DRV8874-Devboard.kicad_pcb, DRV8874-Devboard.kicad_sch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]
2026-09-14 updated WireLib
2026-09-14 updated EEPROM driver
2026-09-14 added base firmware for testing i2c comms
2026-09-15 added firmware for testing i2c
2026-09-15 addded i2c
2026-09-15 started working on i2c
2026-09-17 added i2c read
2026-09-17 started working on canbus
2026-09-17 added canbus to firmware
2026-09-17 omg canbus works

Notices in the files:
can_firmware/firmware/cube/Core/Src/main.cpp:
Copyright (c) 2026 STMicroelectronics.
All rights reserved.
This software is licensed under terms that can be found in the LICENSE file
